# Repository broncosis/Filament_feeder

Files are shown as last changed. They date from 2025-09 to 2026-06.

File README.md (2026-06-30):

# Filament Feeder

> **Use this at your own risk.** This is how I did it — not the only way, and definitely not the officially supported way. That said, it works great on my setup and should be adaptable to most Klipper-based toolchangers with minor tweaks.

This project adds automated filament loading to a Klipper toolchanger. Filament sits outside the machine on a per-tool feeder extruder, and is pushed through a Bowden tube to the toolhead on demand. It was developed and tested on a Stealth Changer but the approach should work on any Klipper-based toolchanger.

Loading can be triggered automatically by a filament runout/insert sensor, or manually via macro. There are macros for both sensor-based and fixed-distance (no sensor) loading.

---

## Installation

Run this one-liner on your printer's SSH session — no cloning required:

```bash
bash <(curl -fsSL https://raw.githubusercontent.com/broncosis/Filament_feeder/main/install.sh)
```

The installer will detect your Klipper and config directories, then ask which sync module you want.

Two options are available:

### Option 1 — Belay (stable)

Uses [Annex Engineering's Belay](https://github.com/Annex-Engineering/Belay) for single-sensor buffer sync. This is the stable, well-tested path. The installer clones and runs the Belay installer automatically, then copies `feeder.cfg`, `exampleT0.cfg`, and `clean_nozzle.cfg` into your Klipper config directory.

### Option 2 — TurtleNeck Buffer (experimental)

> **⚠️ Still in testing.** This option works on my printer but may have bugs, and the configuration format could change. Try it if you're comfortable debugging Klipper extras.

A custom Klipper extra that replaces Belay with a two-sensor buffer sync and built-in jam detection. The installer drops `turtleneck_buffer.py` into your Klipper extras directory and copies the config files. No separate repo to clone — it's self-contained.

See the [TurtleNeck Buffer section](#turtleneck-buffer) below for full configuration details.

---

## How It Works

Each tool gets its own dedicated feeder extruder mounted externally. When filament is inserted (or a load command is issued), the feeder pushes filament down the Bowden tube toward the toolhead. A buffer/sync module on each feeder keeps things in sync with the toolhead extruder during printing.

Loading flow:
1. Tool is selected and toolhead moves to the purge bucket
2. Feeder does a fast blind pre-feed for most of the Bowden length
3. Sensor-checking loop kicks in for the final stretch (or fixed distance if no toolhead sensor)
4. Once filament is detected at the toolhead (or distance is reached), nozzle heats, purges, and cleans

---

## Hardware Requirements

Per tool you'll need:
- **1 feeder extruder** — I used BMG clones; they push faster than Sherpa Minis down long Bowden runs, but Sherpas work too (mount included). Any extruder with a fitting to secure the PTFE will work.
- **1 stepper driver** — I used a spare 8-bit board with 5 stepper drivers
- **1 Belay sensor** (Option 1) *or* **2 switch inputs for TurtleNeck Buffer** (Option 2) — for sync feedback during printing
- **2 input pins for the BTT Smart Sensor** (optional — a simple filament switch or even a button works fine)
- **1 optional unload button** — I used a 6mm tactile button per tool, wired to the feeder board

So roughly 3–5 input pins + 1 stepper driver per tool.

For the feeder extruder itself, I've included:
- A BMG mount with integrated filament switch and SFS2 sensor bracket (`bmg_sfs2mount.stl`, `bmg_sfs2mount_with button.stl`)
- A Sherpa Mini test mount (`sherpamount.stl`) — works but BMG pushes faster
- STEP file for the BMG mount if you want to modify it (`BMG_Extruder.STEP`)

For the Sherpa Mini variant with ECAS fitting and integrated filament sensor, see [this Printables model](https://www.printables.com/model/999921-sherpa-mini-with-ecas-and-integrated-filament-sens).

---

## Prerequisites

Your printer needs to have working:
- Homing and Quad Gantry Level (QGL) — the macros check for these before doing anything
- A **purge bucket and brush** — loading and unloading both move to the bucket
- A **`CLEAN_NOZZLE` macro** — called after purging to wipe the nozzle

A sample `CLEAN_NOZZLE` macro is included in `clean_nozzle.cfg`. The key variables to tune for your setup are:

| Variable | Description | Default |
|---|---|---|
| `start_x` | X position of the left edge of the brush | `30` |
| `start_y` | Y position of the brush | `-1` |
| `start_z` | Z height to wipe at | `0.7` |
| `wipe_dist` | Length of the brush in mm | `32` |
| `wipe_times` | Number of wipe passes | `8` |
| `wipe_speed` | Wipe speed in mm/s | `200` |
| `min_temp` | Minimum temp before wiping (heats to this if lower) | `150` |

The macro uses whatever temperature the nozzle was already targeting — it only heats to `min_temp` if the nozzle is cold, then restores the original target when done.

```ini
[gcode_macro CLEAN_NOZZLE]
variable_start_x: 30          # X position of the left edge of the brush
variable_start_y: -1          # Y position of the brush
variable_start_z: 0.7         # Z height to wipe at
variable_wipe_dist: 32        # Length of the brush in mm
variable_wipe_times: 8        # Number of wipe passes
variable_wipe_speed: 200      # Wipe speed in mm/s
variable_raise_distance: 25   # Z raise after wiping
variable_min_temp: 150        # Minimum temp to wipe at (heats up if below this)
gcode:
    {% if "xyz" not in printer.toolhead.homed_axes %}
        G28
    {% endif %}
    RESPOND TYPE=echo MSG="Cleaning nozzle"
    {% set heater = printer.toolhead.extruder %}
    {% set target_temp = printer[heater].target %}
    {% if target_temp < min_temp %}
        M104 S{min_temp}
    {% endif %}
    G90
    G1 X{start_x + (wipe_dist/2)} Y{start_y} F12000
    TEMPERATURE_WAIT SENSOR={heater} MINIMUM={min_temp}
    G1 Z{start_z} F1500
    G1 X{start_x} F{wipe_speed * 60}
    {% for wipes in range(1, (wipe_times + 1)) %}
        G1 X{start_x + wipe_dist} F{wipe_speed * 60}
        G1 X{start_x} F{wipe_speed * 60}
    {% endfor %}
    G1 Y0 X60
    G1 Y4 X60
    G1 Z{raise_distance}
    M104 S{target_temp}
```

---

## Files in This Repo

| File | Description |
|---|---|
| `install.sh` | Installer — choose Belay (stable) or TurtleNeck Buffer (experimental) |
| `feeder.cfg` | Main config — feeder MCU, Belay tensioners, feeder steppers, unload buttons, and all macros |
| `exampleT0.cfg` | Sample tool config — EBB CAN toolhead board, extruder, hotend fan, part fan, ADXL345, toolchanger tool definition, and all three filament sensors |
| `clean_nozzle.cfg` | Nozzle wipe macro |
| `turtleneck_buffer/` | TurtleNeck Buffer Klipper extra, install script, and example configs *(experimental)* |
| `bmg_sfs2mount.stl` | BMG feeder mount with SFS2 sensor bracket |
| `bmg_sfs2mount_with button.stl` | Same but with tactile unload button |
| `sherpamount.stl` | Sherpa Mini feeder mount (test variant) |
| `BMG_Extruder.STEP` | STEP source for the BMG mount |
| `side panel spacer.stl` | Spacer for side panel mounting |

---

## Configuration

Run `bash install.sh` to copy config files, or copy them manually. Add `[include feeder.cfg]` to your `printer.cfg`.

You'll need to update:
- **MCU serial path** — match your feeder board's USB ID
- **Sensor and button pins** — match your feeder board's pinout
- **`extruder_stepper` extruder names** — match your tool definitions (e.g. `extruder`, `extruder1`, etc.)
- **`rotation_distance`** — tuned for BMG 50:17 gear ratio; re-calibrate if using a different extruder
- **Purge bucket coordinates** (`bucket_x`, `bucket_y`) — set these to your bucket position
- **Bowden tube length** (`D` parameter, default `1400`) — measure your actual tube length

### Belay tensioner setup

Add the relevant Belay settings to your `printer.cfg` as documented in the [Belay repo](https://github.com/Annex-Engineering/Belay). Each tool's Belay section in `feeder.cfg` references its corresponding `extruder_stepper`.

### Toolhead filament sensors

Each tool uses up to three sensors, all defined in the tool's config file (e.g. `T0.cfg`). See the included `exampleT0.cfg` for a complete working example.

**1. Feeder-side switch sensor** (`filament_sensor_T{N}`) — mounted at the feeder extruder on the feeder MCU. Detects insert/runout at the feeder end and triggers `LOAD_ANY_TOOL` on insert:

```ini
[filament_switch_sensor filament_sensor_T0]
switch_pin: ^feeder:PH0
pause_on_runout: FALSE
runout_gcode:
    M118 Runout sensor T0 reports: Runout
insert_gcode:
    M118 Runout sensor T0 reports: Filament Detected
    LOAD_ANY_TOOL T=0 S=30 D=1660
```

**2. Toolhead arrival sensor** (`filament_sensor_at_T{N}`) — mounted on the toolhead board. This is what `LOAD_ANY_TOOL` checks during the feed loop to know when filament has arrived. The name must follow the `filament_sensor_at_T{N}` pattern exactly:

```ini
[filament_switch_sensor filament_sensor_at_T0]
switch_pin: ^EBBT0:PB8
pause_on_runout: FALSE
runout_gcode:
    M118 Runout sensor at T0 reports: No filament detected
insert_gcode:
    M118 Runout sensor at T0 reports: Filament detected
```

**3. Motion encoder sensor** (optional) — detects filament jams during printing by monitoring actual filament movement:

```ini
[filament_motion_sensor encoder_sensor_T0]
switch_pin: ^feeder:PB3
detection_length: 10
extruder: extruder
pause_on_runout: False
runout_gcode:
    {% if printer.print_stats.state == "printing" and not printer.pause_resume.is_paused %}
        PAUSE
        M117 Filament encoder runout
    {% endif %}
```

---

## Macros

### `LOAD_ANY_TOOL` — sensor-based load *(recommended)*

Requires a toolhead filament sensor. Does a fast pre-feed, then steps in small increments checking the sensor until filament is detected, then heats and purges.

```
LOAD_ANY_TOOL T=0 S=30 D=1360
```

| Parameter | Description | Default |
|---|---|---|
| `T` | Tool number | required |
| `S` | Feed speed (mm/s) | `30` |
| `D` | Max feed distance / Bowden length (mm) | `1400` |

### `LOAD_ANY_TOOL_DIST` — fixed-distance load *(no sensor needed)*

Feeds exactly `D` mm. Measure your Bowden tube carefully.

```
LOAD_ANY_TOOL_DIST T=0 S=30 D=1360
```

Same parameters as above.

### `UNLOAD_ANY_TOOL`

Shapes the tip, retracts from the nozzle, then pulls filament back through the Bowden.

```
UNLOAD_ANY_TOOL T=0 S=30 D=1400
```

Unload buttons on the feeder box also call this automatically.

---

## TurtleNeck Buffer

> **⚠️ Experimental — still in testing.** Works on my printer but may have bugs. Configuration format may change.

TurtleNeck Buffer is a custom Klipper extra (`turtleneck_buffer.py`) that replaces Belay with a two-sensor design and adds built-in jam detection. Install it via `install.sh` option 2.

### How it differs from Belay

| | Belay | TurtleNeck Buffer |
|---|---|---|
| Sensors per tool | 1 | 2 (advance + trailing) |
| Sync logic | single threshold | three-state: neutral / advancing / trailing |
| Jam detection | no (uses BTT SFS separately) | built-in |
| Installation | separate repo | single `.py` file, included here |

### Configuration

Add a `[turtleneck_buffer TN]` section for each tool:

```ini
[turtleneck_buffer T0]
advance_pin: feeder:PA0        # buffer expanded — speed up
trailing_pin: feeder:PA1       # buffer compressed — slow down
extruder_stepper: feeder_t0
multiplier_high: 1.05          # speed multiplier when advancing
multiplier_low: 0.95           # speed multiplier when trailing
sensitivity: 5                 # jam detection threshold (0–10, higher = more sensitive)
```

| Parameter | Description |
|---|---|
| `advance_pin` | Switch that triggers when the buffer is fully expanded (filament tension low) |
| `trailing_pin` | Switch that triggers when the buffer is compressed (filament tension high) |
| `extruder_stepper` | Name of the `[extruder_stepper]` to control |
| `multiplier_high` | Speed multiplier applied when advancing (buffer expanded) |
| `multiplier_low` | Speed multiplier applied when trailing (buffer compressed) |
| `sensitivity` | Jam detection sensitivity 0–10. `0` = disabled, `10` = triggers after ~10 mm without buffer movement |

### Available commands

| Command | Description |
|---|---|
| `QUERY_BUFFER BUFFER=T0` | Report current state and rotation_distance |
| `SET_ROTATION_FACTOR BUFFER=T0 FACTOR=1.02` | Directly adjust speed |
| `SET_BUFFER_MULTIPLIER BUFFER=T0 MULTIPLIER=HIGH FACTOR=1.05` | Tune high/low multipliers live |

### Jam detection

When the extruder moves more than `fault_distance` mm without the buffer state changing, the module calls the `TURTLENECK_JAM` macro. You can override this macro to trigger a pause, alert, or custom recovery:

```ini
[gcode_macro TURTLENECK_JAM]
gcode:
    PAUSE
    M117 Filament jam detected on {params.TOOL}
```

If `TURTLENECK_JAM` is not defined, the module logs a warning and continues.

### feeder.cfg with TurtleNeck Buffer

The same `feeder.cfg` is used, but you should **remove or comment out the `[belay]` sections** — TurtleNeck Buffer takes over that role. Everything else (steppers, macros, sensors) stays the same.

---

## Companion Projects

These are separate projects built to improve the experience around this feeder system. Neither is required — the feeder works without them — but together they make toolchanger filament management significantly more polished.

### KlipperScreen Filament Lanes

[broncosis/KlipperScreen-filament-lanes](https://github.com/broncosis/KlipperScreen-filament-lanes)

A custom KlipperScreen panel that gives you a live view of all your filament lanes on the printer touchscreen. Each tool gets a column showing spool color, material, and name pulled from Spoolman, with per-lane filament sensor status and tap-to-select tool switching. Works on 4, 5, 6+ tool setups automatically.

**Requires:** KlipperScreen, Moonraker with Spoolman integration, and the `LOAD_ANY_TOOL_DIST` / `UNLOAD_ANY_TOOL` macros from this repo. Works without spoolman-lane-sync, but shows richer data with it.

Install via the one-liner in that repo — it symlinks the panel into KlipperScreen and adds the config block.

### Spoolman Lane Sync

[broncosis/spoolman-lane-sync](https://github.com/broncosis/spoolman-lane-sync)

A small background service that syncs filament data from Spoolman into Moonraker's database so OrcaSlicer sees which material is loaded in each tool slot. Polls Spoolman every 30 seconds and listens on Moonraker's WebSocket for real-time updates. Backs off automatically if Happy Hare or AFC is already managing that data.

**Requires:** Python 3.10+, Moonraker, Spoolman. Runs as a systemd service and integrates with Moonraker's update manager for OTA updates.

Install by cloning the repo, running `install.sh`, and configuring the `.env` file with your Moonraker/Spoolman addresses.

---

## Credits

**[Annex Engineering](https://github.com/Annex-Engineering)** — for [Belay](https://github.com/Annex-Engineering/Belay), the single-sensor buffer sync module that this project is built around. Great hardware and great software — go check out their stuff.

**[Armoured Turtle](https://github.com/ArmouredTurtle)** — for the TurtleNeck buffer concept and hardware that the `turtleneck_buffer` Klipper extra is designed to work with. The two-sensor approach and the AFC config parameter naming both come from their work.

---

## Questions / Discussion

I've documented this build on the Stealth Changer Discord: https://discordapp.com/channels/1226846451028725821/1401147182639481004

That's probably the best place to ask questions, compare notes, or share variations.

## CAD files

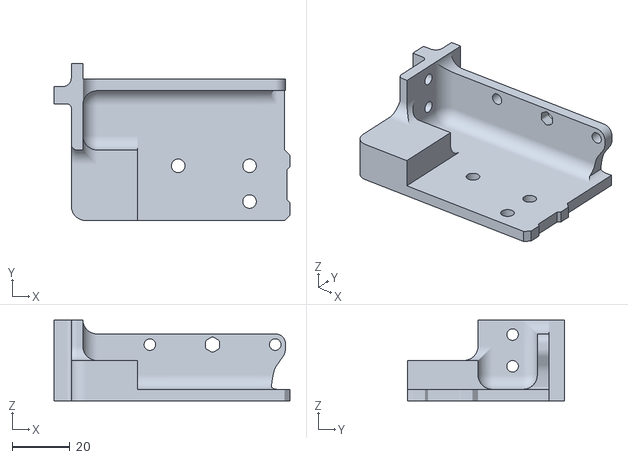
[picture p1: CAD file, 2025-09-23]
sherpamount.stl
81.9 x 54.5 x 28.0

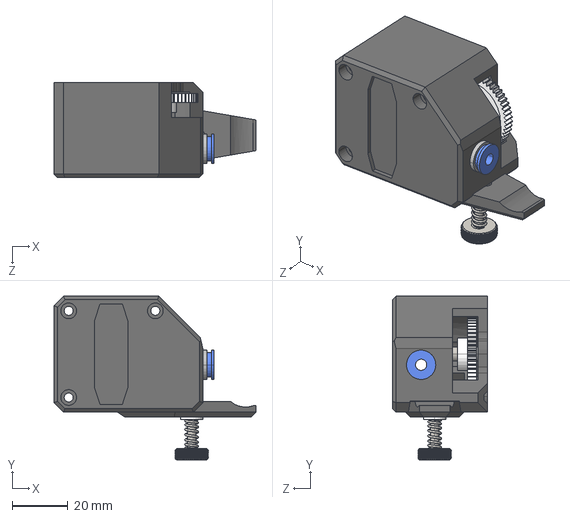
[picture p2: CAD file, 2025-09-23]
BMG_Extruder.STEP
72.2 x 58.6 x 34.0 mm

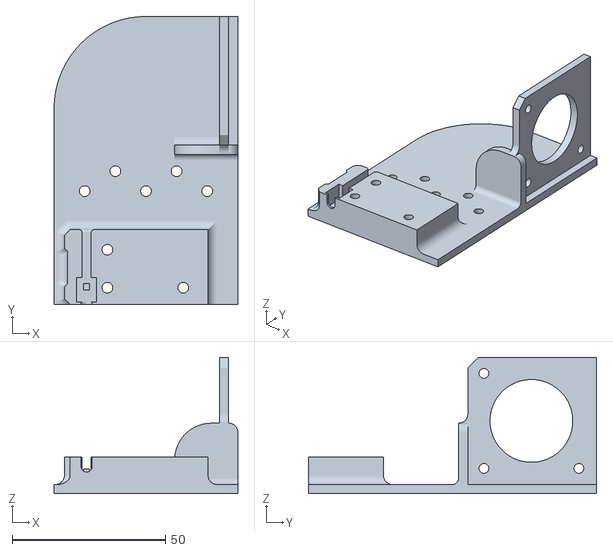
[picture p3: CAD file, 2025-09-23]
bmg_sfs2mount_with button.stl
60.0 x 94.0 x 44.5

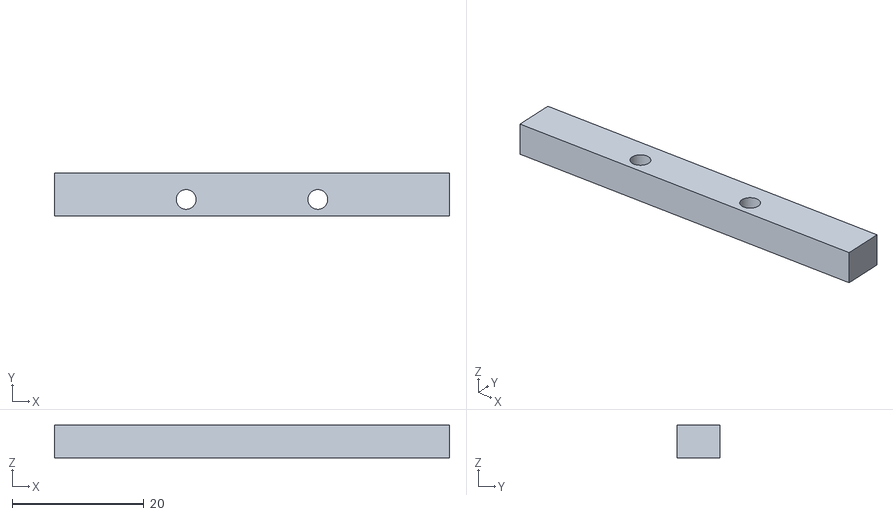
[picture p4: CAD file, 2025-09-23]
side panel spacer.stl
60.0 x 6.50 x 5.00

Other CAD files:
bmg_sfs2mount.stl

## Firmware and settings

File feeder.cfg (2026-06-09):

# =============================================================================
# feeder.cfg — Bowden feeder MCU, steppers, belay tensioners, and load macros
# =============================================================================
# Hardware overview:
#   - Separate "feeder" MCU drives 5 independent Bowden feeder steppers
#   - Each tool has a belay tensioner to compensate for filament slack/tension
#   - Physical unload buttons mounted at each feeder position
#   - filament_sensor_at_T{N} (toolhead) defined in tool{N}.cfg
# =============================================================================


# -----------------------------------------------------------------------------
# MCU
# -----------------------------------------------------------------------------

[mcu feeder]
serial: /dev/serial/by-id/usb-Silicon_Labs_CP2102_USB_to_UART_Bridge_Controller_0001-if00-port0


# -----------------------------------------------------------------------------
# Belay tensioners — compensate for filament slack between feeder and toolhead
# multiplier_high/low set the speed ratio bounds before belay intervenes
# -----------------------------------------------------------------------------

[belay tool0_belay]
extruder_type: extruder_stepper
extruder_stepper_name: _tool0_feeder
sensor_pin: ^!feeder:PD3
multiplier_high: 1.05
multiplier_low: 0.95
debug_level: 1

[belay tool1_belay]
extruder_type: extruder_stepper
extruder_stepper_name: _tool1_feeder
sensor_pin: ^!feeder:PJ0
multiplier_high: 1.05
multiplier_low: 0.95
debug_level: 1

[belay tool2_belay]
extruder_type: extruder_stepper
extruder_stepper_name: _tool2_feeder
sensor_pin: ^!feeder:PJ1
multiplier_high: 1.05
multiplier_low: 0.95
debug_level: 1

[belay tool3_belay]
extruder_type: extruder_stepper
extruder_stepper_name: _tool3_feeder
sensor_pin: ^!feeder:PE4
multiplier_high: 1.05
multiplier_low: 0.95
debug_level: 1

[belay tool4_belay]
extruder_type: extruder_stepper
extruder_stepper_name: _tool4_feeder
sensor_pin: ^!feeder:PE5
multiplier_high: 1.05
multiplier_low: 0.95
debug_level: 1


# -----------------------------------------------------------------------------
# Physical unload buttons — one per tool, mounted at the feeder box
# D=1400 should match your bowden tube length in mm
# -----------------------------------------------------------------------------

[gcode_button t0_unload_button]
pin: ^!feeder:PD2
press_gcode:
    UPDATE_DELAYED_GCODE ID=_t0_unload_debounce DURATION=0.5

[delayed_gcode _t0_unload_debounce]
gcode:
    UNLOAD_ANY_TOOL T=0 D=1400 S=30

[gcode_button t1_unload_button]
pin: ^!feeder:PK4
press_gcode:
    UPDATE_DELAYED_GCODE ID=_t1_unload_debounce DURATION=0.5

[delayed_gcode _t1_unload_debounce]
gcode:
    UNLOAD_ANY_TOOL T=1 D=1400 S=30

[gcode_button t2_unload_button]
pin: ^!feeder:PK7
press_gcode:
    UPDATE_DELAYED_GCODE ID=_t2_unload_debounce DURATION=0.5

[delayed_gcode _t2_unload_debounce]
gcode:
    UNLOAD_ANY_TOOL T=2 D=1400 S=30

[gcode_button t3_unload_button]
pin: ^!feeder:PK6
press_gcode:
    UPDATE_DELAYED_GCODE ID=_t3_unload_debounce DURATION=0.5

[delayed_gcode _t3_unload_debounce]
gcode:
    UNLOAD_ANY_TOOL T=3 D=1400 S=30

[gcode_button t4_unload_button]
pin: ^!feeder:PK5
press_gcode:
    UPDATE_DELAYED_GCODE ID=_t4_unload_debounce DURATION=0.5

[delayed_gcode _t4_unload_debounce]
gcode:
    UNLOAD_ANY_TOOL T=4 D=1400 S=30


# -----------------------------------------------------------------------------
# Feeder steppers — one BMG-style extruder stepper per tool
# rotation_distance tuned for 50:17 gear ratio on BMG
# -----------------------------------------------------------------------------

[extruder_stepper _tool0_feeder]
extruder: extruder
step_pin: feeder:PF0
dir_pin:  feeder:PF1
enable_pin: !feeder:PD7
microsteps: 16
full_steps_per_rotation: 200
gear_ratio: 50:17
rotation_distance: 22.319100012672

[tmc2208 extruder_stepper _tool0_feeder]
uart_pin: feeder:PG5
run_current: .5
hold_current: .05
stealthchop_threshold: 250

[extruder_stepper _tool1_feeder]
extruder: extruder1
step_pin: feeder:PF6
dir_pin: feeder:PF7
enable_pin: !feeder:PF2
microsteps: 16
full_steps_per_rotation: 200
gear_ratio: 50:17
rotation_distance: 22.319100012672

[tmc2208 extruder_stepper _tool1_feeder]
uart_pin: feeder:PE3
run_current: .5
hold_current: .05
stealthchop_threshold: 250

[extruder_stepper _tool2_feeder]
extruder: extruder2
step_pin: feeder:PL3
dir_pin:  feeder:PL1
enable_pin: !feeder:PK0
microsteps: 16
full_steps_per_rotation: 200
gear_ratio: 50:17
rotation_distance: 22.319100012672

[tmc2208 extruder_stepper _tool2_feeder]
uart_pin: feeder:PH3
run_current: .5
hold_current: .05
stealthchop_threshold: 250

[extruder_stepper _tool3_feeder]
extruder: extruder3
step_pin: feeder:PA4
dir_pin: !feeder:PA6
enable_pin: !feeder:PA2
microsteps: 16
full_steps_per_rotation: 200
gear_ratio: 50:17
rotation_distance: 22.319100012672

[tmc2208 extruder_stepper _tool3_feeder]
uart_pin: feeder:PB5
run_current: .5
hold_current: .05
stealthchop_threshold: 250

[extruder_stepper _tool4_feeder]
extruder: extruder4
step_pin: feeder:PC1
dir_pin: !feeder:PC3
enable_pin: !feeder:PC7
microsteps: 16
full_steps_per_rotation: 200
gear_ratio: 50:17
rotation_distance: 22.319100012672

[tmc2208 extruder_stepper _tool4_feeder]
uart_pin: feeder:PB6
run_current: .5
hold_current: .05
stealthchop_threshold: 250


# -----------------------------------------------------------------------------
# Safety guard — called at the start of every load/unload macro
# Raises an error (halts execution) if any condition is not met
# -----------------------------------------------------------------------------

[gcode_macro _CHECK_READY]
description: Abort if machine is not homed, QGL not applied, or actively printing
gcode:
    {% if printer.toolhead.homed_axes != "xyz" %}
        { action_raise_error("Machine not homed.") }
    {% elif printer.quad_gantry_level.applied|lower == 'false' %}
        { action_raise_error("QGL not applied.") }
    {% elif printer.print_stats.state == "printing" and not printer.pause_resume.is_paused %}
        { action_raise_error("Print is active. Pause or cancel before loading/unloading.") }
    {% endif %}


# -----------------------------------------------------------------------------
# LOAD_ANY_TOOL — sensor-based load
# Positions toolhead at purge bucket then calls _FILAMENT_FEED. Heating and
# purging happen in _LOAD_COMPLETE once the toolhead sensor triggers.
#
# Parameters:
#   T = tool index
#   S = feeder speed in mm/s (default 30)
#   D = max feed distance / bowden length in mm (default 1400)
# -----------------------------------------------------------------------------

[gcode_macro LOAD_ANY_TOOL]
description: [T<index>] [S<speed>] [D<distance>] Load filament using sensor feedback
variable_purge:     150  # mm to purge after filament reaches toolhead
variable_bucket_x:   25  # X position of purge bucket
variable_bucket_y:   -4  # Y position of purge bucket
variable_load_temp: 220  # temperature to purge at
variable_dist:       10  # step size passed to _FILAMENT_FEED loop (mm)
variable_paused:      0  # tracks pause state for _LOAD_COMPLETE
gcode:
    _CHECK_READY
    {% set T = params.T|int %}
    {% set speed = params.S|default(30)|float %}
    {% set max_dist = params.D|default(1400)|float %}
    {% set paused = printer.pause_resume.is_paused %}

    {% if printer.toolchanger.tool_number|int != T %}
        RESPOND MSG="Switching to tool {T}"
        T{T}
    {% endif %}

    SET_GCODE_VARIABLE MACRO=LOAD_ANY_TOOL VARIABLE=paused VALUE={1 if paused else 0}

    G90
    {% if not paused %}
        {% if printer.toolhead.position.z < 20 %}
            G1 Z20 F900
        {% endif %}
        G1 X{bucket_x} Y{bucket_y} F1800
    {% else %}
        M118 Print is paused: skipping move to purge bucket
    {% endif %}

    M104 S{load_temp}
    _FILAMENT_FEED T={T} S={speed} MAX={max_dist} D={dist}


# -----------------------------------------------------------------------------
# _LOAD_COMPLETE — called by _FILAMENT_FEED_LOOP when sensor triggers
# Heats, purges, and cleans up. Reads context from LOAD_ANY_TOOL variables.
# -----------------------------------------------------------------------------

[gcode_macro _LOAD_COMPLETE]
gcode:
    {% set T = printer["gcode_macro _FILAMENT_FEED"].tool|int %}
    {% set load_temp = printer["gcode_macro LOAD_ANY_TOOL"].load_temp %}
    {% set purge = printer["gcode_macro LOAD_ANY_TOOL"].purge %}
    {% set paused = printer["gcode_macro LOAD_ANY_TOOL"].paused|int %}

    M109 S{load_temp}
    M83
    G1 E{purge} F300
    G1 E-5 F1800
    M82
    M400

    {% if not paused %}
        CLEAN_NOZZLE
        M104 S0
    {% endif %}

    M118 Tool {T} loaded
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

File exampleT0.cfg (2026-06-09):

# This file contains common pin mappings for the BIGTREETECH EBBT0
# Canbus board. To use this config, the firmware should be compiled for the
# STM32G0B1 with "8 MHz crystal" and "USB (on PA11/PA12)" or "CAN bus (on PB0/PB1)".
# The "EBB Can" micro-controller will be used to control the components on the nozzle.

# See docs/Config_Reference.md for a description of parameters.

[mcu EBBT0]
canbus_uuid: 3dba739e278a
# python3 ~/katapult/scripts/flashtool.py -i can0 -u ac5f7df1a805 -r
# python3 ~/katapult/scripts/flashtool.py -i can0 -u ac5f7df1a805 -f ~/klipper/out/klipper.bin

[adxl345 T0]
cs_pin: EBBT0: PB12
spi_software_sclk_pin: EBBT0: PB10
spi_software_mosi_pin: EBBT0: PB11
spi_software_miso_pin: EBBT0: PB2
axes_map: x,z,-y

[extruder]
step_pin: EBBT0: PD0
dir_pin: !EBBT0: PD1
enable_pin: !EBBT0: PD2
heater_pin: EBBT0: PB13
sensor_pin: EBBT0: PA3
sensor_type: ATC Semitec 104NT-4-R025H42G
rotation_distance: 22.319100012672 #53.58 
gear_ratio: 50:10, #37:17
microsteps: 16
full_steps_per_rotation: 200 #1.8deg Motor
max_extrude_only_distance: 1400.0
max_extrude_only_velocity: 75.0
max_extrude_only_accel: 1500
nozzle_diameter: 0.400
filament_diameter: 1.750
max_extrude_cross_section: 0.64

control: pid
pid_Kp: 39.661
pid_Ki: 4.407
pid_Kd: 89.238

#pid_Kp=25.596 
#pid_Ki=4.162 
#pid_Kd=39.354

# pid_Kp=27.143 
# pid_Ki=7.238 
# pid_Kd=25.447

# pid_Kp=25.953 
# pid_Ki=6.921 
# pid_Kd=24.332

min_temp: -10
max_temp: 300
min_extrude_temp: 170
pressure_advance: 0.04                                               # See tuning pressure advance doc
pressure_advance_smooth_time: 0.066



[tmc2209 extruder]
uart_pin: EBBT0: PA15
run_current: 0.45
hold_current: 0.1
driver_TPOWERDOWN: 20
stealthchop_threshold: 999999

[heater_fan T0_hotend_fan]
pin: EBBT0: PA0
heater: extruder
heater_temp: 50.0
kick_start_time: 0.5

[fan_generic T0_partfan]
pin: EBBT0: PA1
kick_start_time: 0.25
cycle_time: 0.15
off_below: 0.10

[gcode_macro T0]
variable_active: 0
variable_color: ""
variable_spool_id: None
gcode:
    SELECT_TOOL T=0
    SET_ACTIVE_SPOOL ID={printer["gcode_macro T0"].spool_id}

#change the tool numbers to the tool you are configuring, ie T0, T1, etc
[tool T0]
#change this too
tool_number: 0
detection_pin: !EBBT0:PB6
gcode_x_offset: 0
gcode_y_offset: 0
gcode_z_offset: 0
#if this were T1, then this would be extruder1, etc
extruder: extruder
#Change T0_partfan to tool number
fan: T0_partfan
#These are build specific, its where the tool is sititng in it's dock.
params_park_x: 54.1
params_park_y: 16
params_park_z: 340.000
# For InputShaper run per tool and enter the frequency here
params_input_shaper_type_x: 'mzv'
params_input_shaper_freq_x: 46.4
params_input_shaper_damping_ratio_x: 0.098
params_input_shaper_type_y: 'mzv'
params_input_shaper_freq_y: 34.4
params_input_shaper_damping_ratio_y: 0.088

# [neopixel T0_leds]
# pin: EBBT0:PD3
# chain_count: 3
# color_order: GRB
# initial_RED: 1.0
# initial_GREEN: 0.0
# initial_BLUE: 0.0
# initial_WHITE: 0.0

[gcode_macro _T0_vars]
variable_logo_led_name:         "T0_leds"
variable_logo_idx:              "1"
variable_nozzle_led_name:       "T0_leds"
variable_nozzle_idx:            "2,3"
gcode:



[filament_switch_sensor filament_sensor_T0]
switch_pin: ^feeder:PH0
pause_on_runout: FALSE
runout_gcode:
  M118 Runout sensor T0 reports: Runout
insert_gcode:
  M118 Runout sensor T0 reports: Filament Detected
  LOAD_ANY_TOOL T=0 S=30 D=1660

[filament_motion_sensor encoder_sensor_T0]
switch_pin: ^feeder:PB3
detection_length: 10
extruder: extruder
pause_on_runout: False
runout_gcode:
  {% if printer.print_stats.state == "printing" and not printer.pause_resume.is_paused %}
    PAUSE
    M117 Filament encoder runout
  {% endif %}
insert_gcode:
  M117 Filament encoder inserted

[filament_switch_sensor filament_sensor_at_T0]
switch_pin: ^EBBT0:PB8
pause_on_runout: FALSE
runout_gcode:
  M118 Runout sensor at T0 reports: No filament Detected
insert_gcode:
  M118 Runout sensor at T0 reports: Filament Detected

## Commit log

2026-06-01 removed the need for dynamic macros
    [feeder.cfg]
2026-06-01 Delete dynamic.cfg
    no longer needed
    [dynamic.cfg]
2026-06-09 Clean up README and update feeder.cfg
    - Rewrote README with structured sections
    - Fixed sensor name to filament_sensor_at_T{N}
    - feeder.cfg: added debounce on unload buttons
    - feeder.cfg: corrected sensor name pattern
    [T0.cfg]
2026-06-09 Clean up README, update feeder.cfg, add sample T0 tool config
    [feeder.cfg]
2026-06-09 Clean up README, update feeder.cfg, add sample T0 tool config add claen nozzle.cfg
    [clean_nozzle.cfg]
2026-06-09 Add install.sh, rename T0.cfg, update README with two install options
    - Add install.sh: interactive installer for Belay (stable) or TurtleNeck
    Buffer (experimental); auto-detects Klipper and config dirs, handles
    fetching turtleneck files from the git branch if not on it locally
    - Rename T0.cfg -> exampleT0.cfg for clarity
    - README: add Installation section explaining both options up front, add
    TurtleNeck Buffer section with config reference and comparison table,
    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
    [exampleT0.cfg]
2026-06-09 Update installer: curl one-liner, auto-install Belay, download files when run standalone
    - install.sh now works when piped via curl (detects IN_REPO, downloads
    files from raw.githubusercontent.com when not running from a clone)
    - Belay option now clones Annex Engineering/Belay and runs their installer
    automatically instead of just pointing users to the repo
    - Offers Klipper restart after Belay install (same as TurtleNeck path)
    - README Installation section replaced with curl one-liner
2026-06-30 Add Companion Projects section and .gitignore
    Documents KlipperScreen-filament-lanes and spoolman-lane-sync as
    related projects in the README. Adds .gitignore to exclude .claude/.
